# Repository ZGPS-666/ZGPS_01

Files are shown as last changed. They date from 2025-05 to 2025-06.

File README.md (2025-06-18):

# ZGPS_01
一种可在球形和六足形态切换的可变形机器人设计与开发

本项目旨在尝试复刻项目MorpHex，原作者ZentaRobotics视频主页如下：https://www.youtube.com/@ZentaRobotics

3D模型文件请使用solidworks 2024及以上版本打开，钣金件所需数目已在文件名标注，3D打印可转至makerworld，已切片，方便打印:https://makerworld.com.cn/zh/models/1331257-qiu-xing-liu-zu-shuang-xing-tai-ji-qi-ren#profileId-1434366

PCB工程请转至嘉立创EDA：https://oshwhub.com/zgps/spherical-hexapod-biped-robot

## 视频链接：
[B站视频--功能演示及介绍](https://www.bilibili.com/video/BV1fMJgzxEva/)
## 项目简介
一种可在球形和六足形态切换的可变形机器人设计与开发

本项目旨在尝试复刻项目morphex，同时作为本人本科毕业设计题目，原作者视频主页如下：https://www.youtube.com/@ZentaRobotics

项目源码及3D模型请转至GitHub：
https://github.com/ZGPS-666/ZGPS_01

## 项目功能
作为本人首个独立完成的完整机器人系统项目，在有限的开发周期内，项目重点聚焦于核心功能的复现与验证。当前版本已成功实现机器人的基本运动能力，包括六足步态行走、球形滚动和形态切换功能。

本设计是基于STM32F407ZGT6微控制器的多形态变形机器人系统，使用STM32CUBEIDE开发：
- **六足行走模式**：支持直线前进、侧向移动、原地旋转等多种运动方式，采用三角步态实现稳定行走；
- **球形滚动模式**：通过12个切片的协调控制实现前进、后退、左转、右转等全方向滚动运动；
- **自动变形功能**：实现两种形态间的平稳切换；
- **多种控制方式**：支持遥控器控制和语音识别控制，提供灵活的人机交互方式；

## 项目参数
* 六足模式行走速度：≥0.2m/s，具备全向移动和精确转向能力；
* 球形模式滚动速度：≥0.5m/s，运动效率显著提升；
* 形态切换时间：<30秒，具有较高的成功率和可靠性；
* 球形结构直径：400mm，由6个环向分布的可控切片组成；
* 驱动系统：30个20kg·cm串口总线舵机 + 1个70kg·cm数字舵机；
* 工作电压：7.4V，续航能力：9000mAh大容量航模电池；
* 通信方式：2.4GHz无线遥控 + 离线语音识别；

## 原理解析（硬件说明）
本项目由以下核心部分组成：主控制系统、驱动系统、变形机构、通信系统和供电系统。
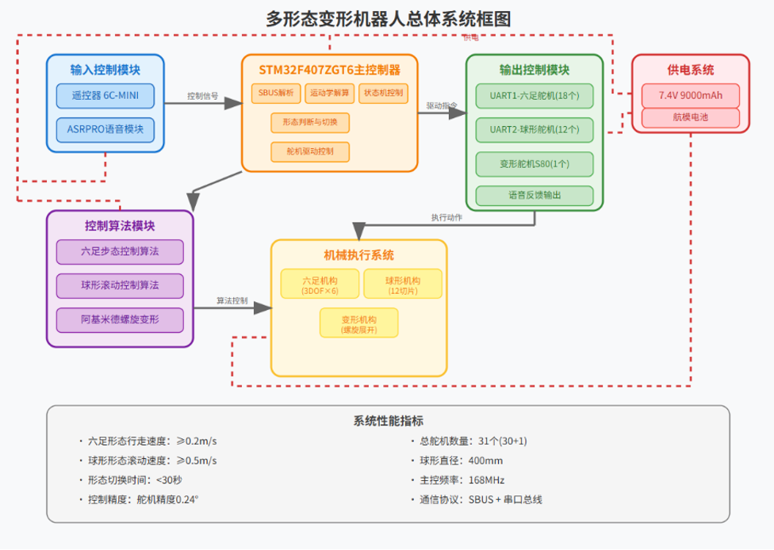
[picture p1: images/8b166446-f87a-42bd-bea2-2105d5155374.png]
  

**主控制系统**：采用STM32F407ZGT6微控制器，168MHz主频，1M Flash + 192K SRAM，提供6个UART接口满足多舵机通信需求。集成了运动学解算、步态控制、形态切换等核心算法。

**驱动系统电路**：使用AIP74HC126TA.TB四路三态缓冲器实现串口信号的电平转换和驱动增强。30个ZX20D总线舵机负责腿部运动和切片控制，1个S80舵机专门驱动变形机构，满足大扭矩变形需求。

**变形机构设计**：核心采用阿基米德螺旋原理设计的底盘展开机构，通过螺旋形切片在齿轮系统驱动下的轴向旋转，实现六条腿的同步展开和收缩，确保形态切换的稳定性和可靠性。

**通信系统电路**：集成Microzone 6C-MINI遥控器系统，通过MC7RB-V2接收机实现2.4GHz无线控制。SBUS信号经过硬件电平反转电路处理后接入主控。同时集成ASRPRO语音模块，支持离线语音识别控制。

**供电系统**：采用7.4V/9000mAh/10C大功率航模电池，满足六足行走模式下的高功率需求，通过PCB上的电源管理电路为各模块提供稳定供电。

## 软件代码
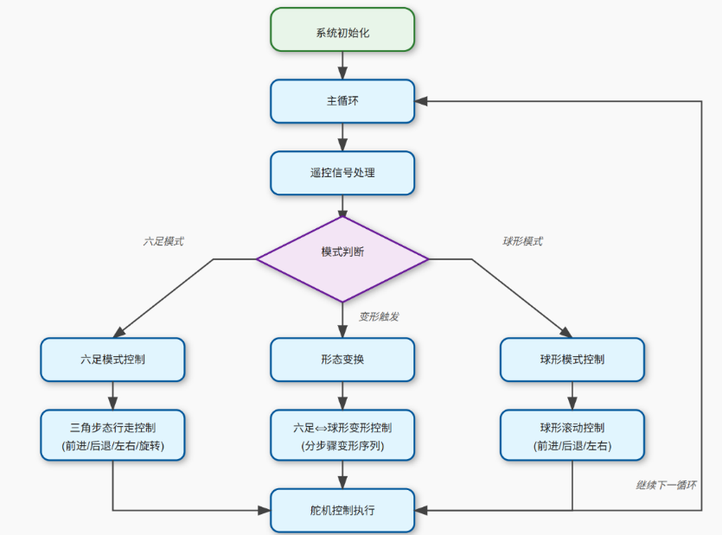
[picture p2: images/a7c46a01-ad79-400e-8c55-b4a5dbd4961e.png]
  
完整代码请参考：(https://github.com/ZGPS-666/ZGPS_01)

## 注意事项

* 所有安装步骤前请先完成总线舵机编号并调至中位，工作模式选择模式一，开机模式选择模式三
* 所有安装步骤前请把中央舵机先设置至30°位置
* 遥控器使用前需要与接收机进行配对，注意SBUS信号的电平转换；
* 电池电压低于6.8V时应及时充电，避免影响大扭矩舵机性能；

## 组装流程
待更新

## 实物图
图1：**六足形态** - 机器人完全展开的六足行走状态
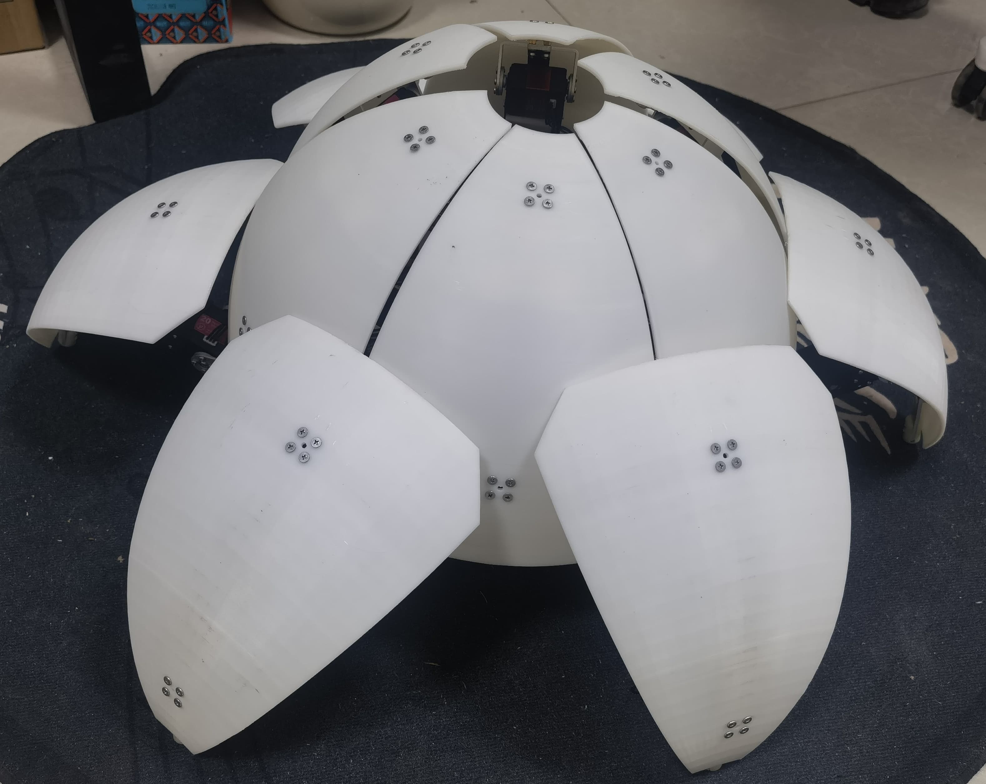
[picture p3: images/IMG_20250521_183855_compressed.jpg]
  

图2：**球形态** - 机器人收缩后的球形滚动状态  
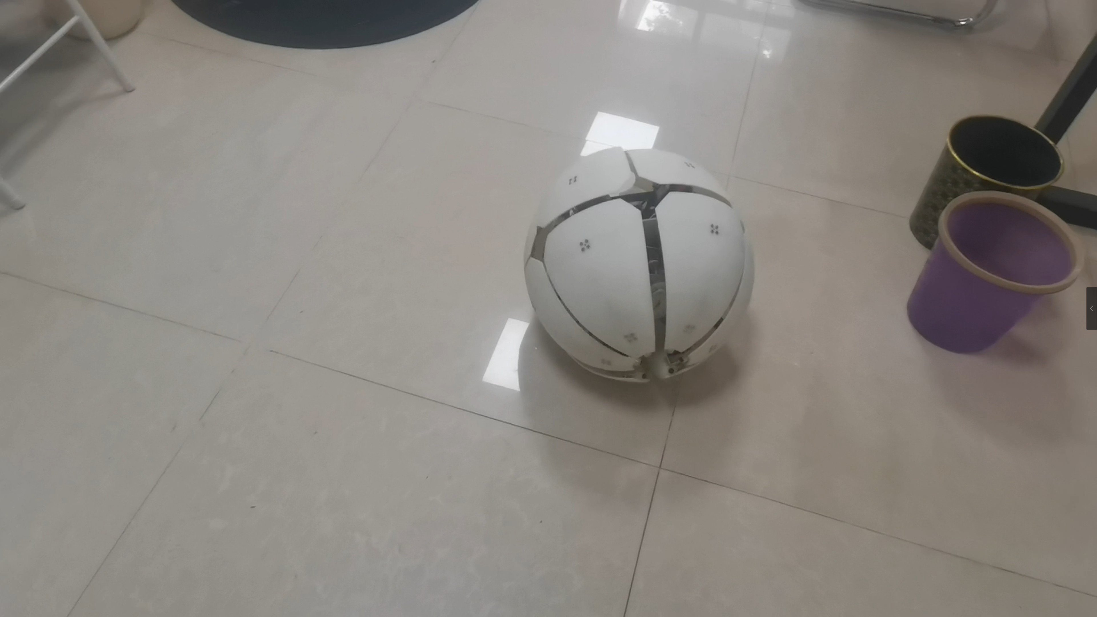
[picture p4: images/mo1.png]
  

图3：**展示模式** - 从六足向球形转换的中间状态
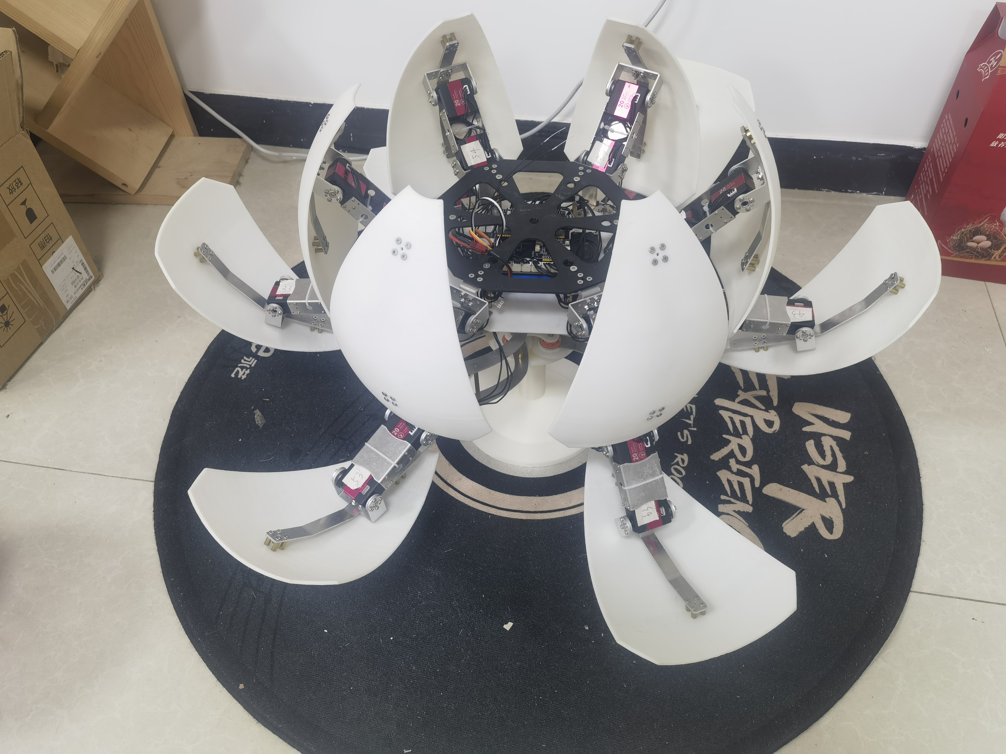
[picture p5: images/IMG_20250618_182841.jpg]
  

## 声明
由于本人水平有限，初次独立完成完整项目，时间仓促，仅完成机器人的基本功能，代码已有堆史山的趋势，所以本项目只能保证机器人能动。

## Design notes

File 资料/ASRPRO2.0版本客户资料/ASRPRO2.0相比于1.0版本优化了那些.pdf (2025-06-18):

我们汲取客户的反馈，对电路进行优化，推出 ASRPRO2.0 版本。

其 ASRPRO 语音识别模块 2.0 版本相比于 1.0，其外形上尺寸继续

延续 1.0 版本，其内部电路进行了优化。

下面详细介绍，2.0 版本都进行了那些优化。

1. 2.0 版本在 5V 和 3.3V 之前加入了 TVS 二极管防止电源过压，保

护芯片。

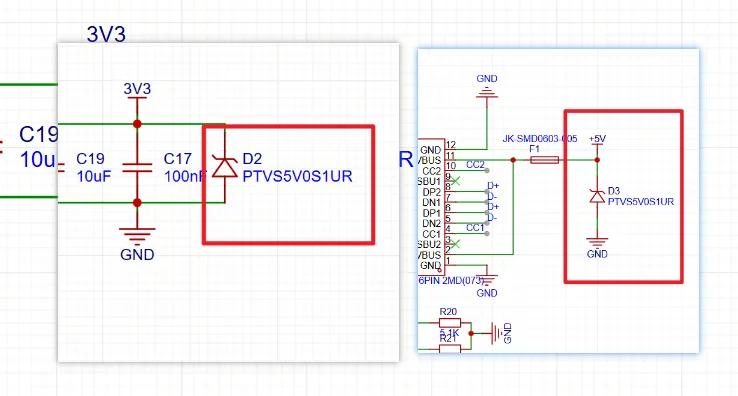
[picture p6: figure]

### 2. ASRPRO-1.0 版本上的 3.3V 输出引脚是由芯片内部引出的，很

多客户接外设时，把 GND 和 VCC 接反会直接烧毁主控芯片。而

ASRPRO-2.0 版本的 3.3V 输出引脚是 LDO 电路输出的，极大的保

护了主控芯片。其次 LDO 输出的电流比主控芯片输出的电流大，因

此 2.0 版本 3.3V 引脚的驱动能力更强。

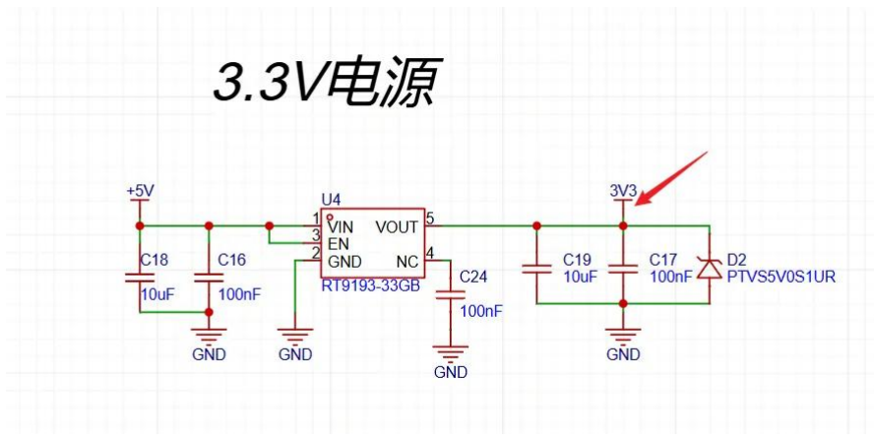
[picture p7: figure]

### 3. 在处理 ASRPRO-1.0 版本的售后时，常会有客户反应，为什么我

开发板下载程序会显示“请是否连接设备 ASR-PRO”。这是因为

ASRPRO 开发板内部一键下载电路出现了问题，无法进行冷启动，

因此在 ASRPRO-2.0 版本上加入了手动下载按键，出现以上情况时，

可以按下按键进行手动冷启动，确保程序能够正常下载。

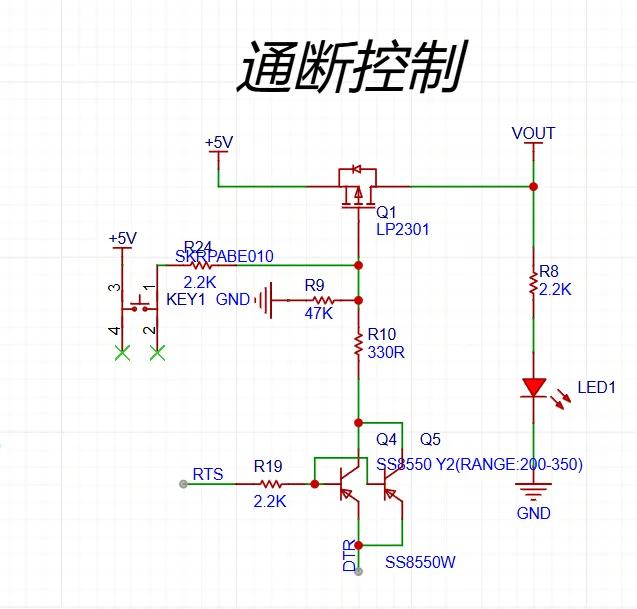
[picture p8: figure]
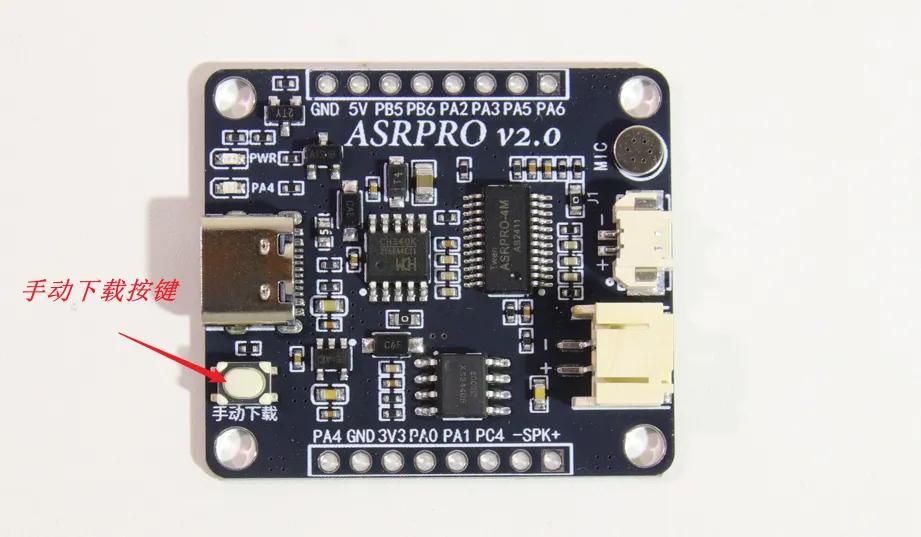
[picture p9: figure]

### 4. 常有客户把 ASRPRO 加上外壳，放到自己的产品中使用，这时

板载的麦克风外面有外壳包裹，导致麦克风识别不灵敏，会影响识别

率。 ASRRPO-2.0 版本加入了 1.25mm 间距麦克风底座，可以用来

外接麦克风,也可以使用板载麦克风，更好的嵌入到产品中，应用场

景更加广泛。

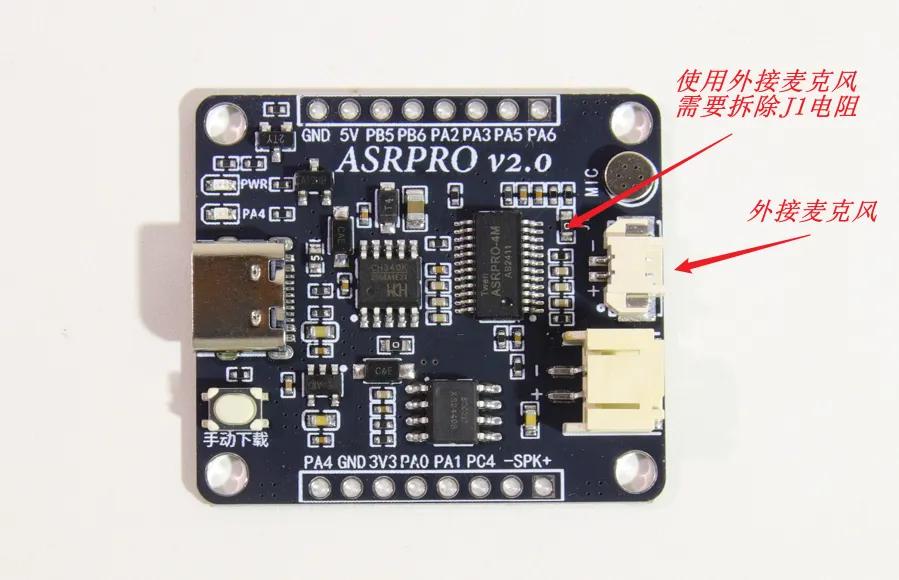
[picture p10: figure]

5.

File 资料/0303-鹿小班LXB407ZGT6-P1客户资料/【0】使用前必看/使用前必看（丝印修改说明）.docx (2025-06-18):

这里丝印标错 E13丝印实际指的是F13

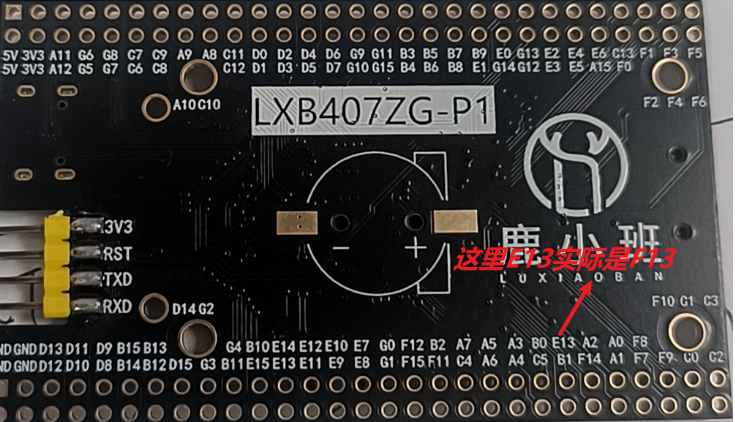
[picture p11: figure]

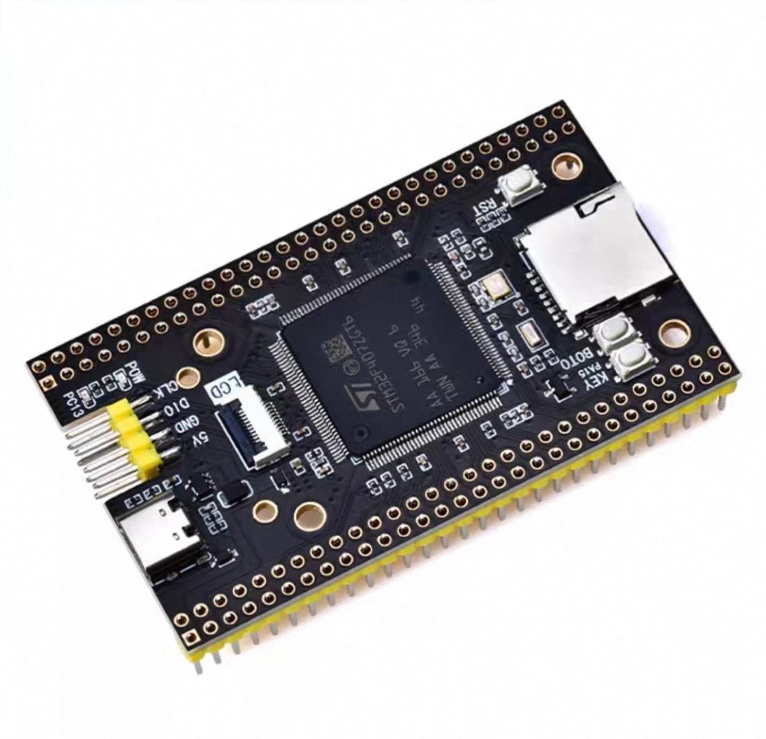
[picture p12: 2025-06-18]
资料/0303-鹿小班LXB407ZGT6-P1客户资料/【4】原理图尺寸图/Screenshot_20250314_162414.jpg

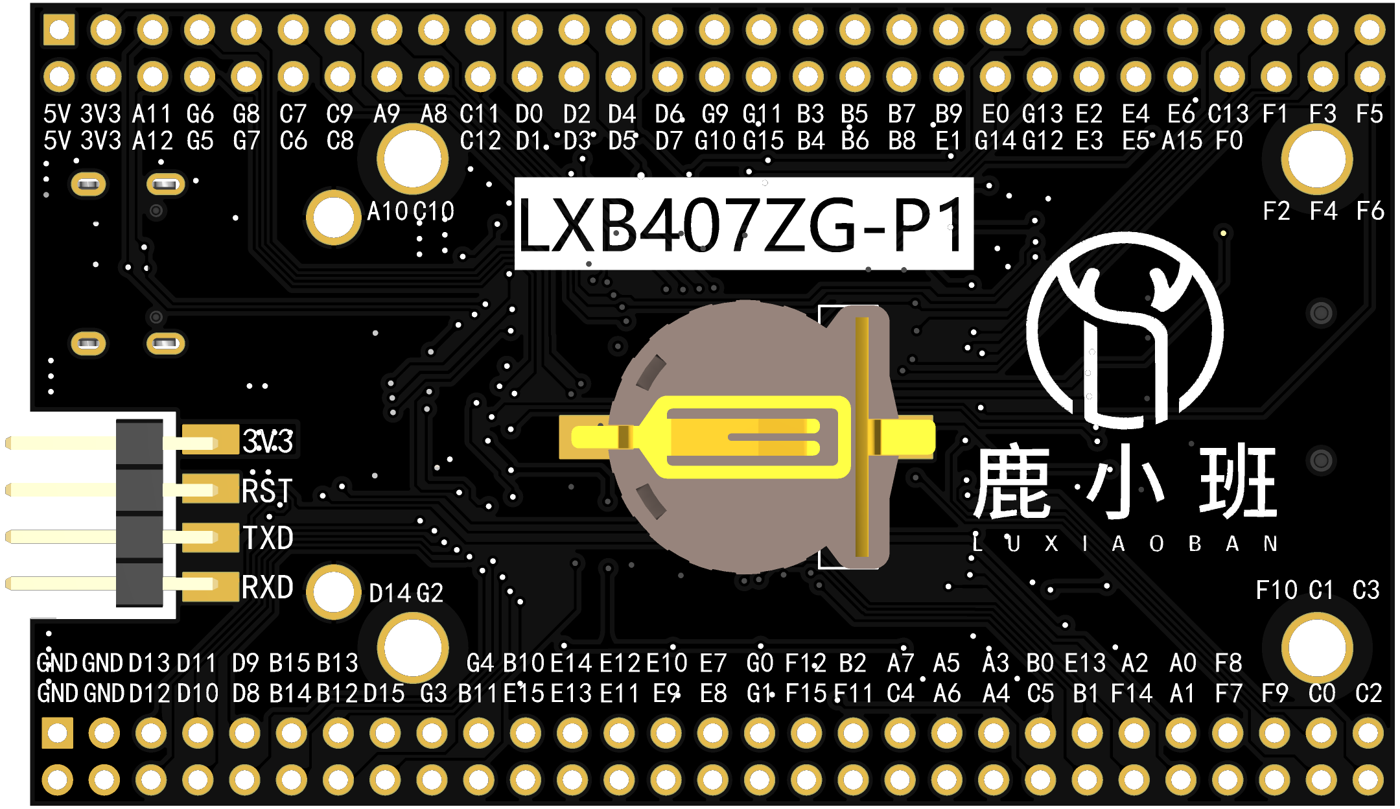
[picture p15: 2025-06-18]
资料/0303-鹿小班LXB407ZGT6-P1客户资料/【4】原理图尺寸图/反面.png

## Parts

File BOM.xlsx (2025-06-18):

物料编号 | 物料描述 | 数量 | 成本 | 总成本 | 备注
1 | 松甲 串行总线舵机 ZX20D | 30 | 66.8 | 1945
2 | 串行舵机连接线 50cm | 6 | 4 | 24
3 | 串行舵机连接线 30cm | 6 | 3 | 18
4 | 星辉S80 180°舵机 | 1 | 288 | 288 | 大扭矩带堵转保护舵机
5 | microzone MC6C遥控器+接收器+电池 | 1 | 150 | 150
6 | 十字扁平头螺丝M3*6 | 200 |  | 13.9 | 螺栓螺母部分数量为我购买数量，实际用不到那么多
7 | 十字扁平头螺丝M3*8 | 300 |  | 23.5
8 | 十字扁平头螺丝M3*10 | 50 |  | 2.9
9 | 十字扁平头螺丝M3*12 | 50 |  | 3.3
10 | 十字扁平头螺丝M2*12 | 50 |  | 2.1
11 | 六角螺母M3 | 200 |  | 5.5
12 | 六角螺母M4 | 100 |  | 4.2
13 | 圆柱头螺栓内六角M3*14 | 50 |  | 2.3
14 | 圆柱头螺栓内六角M3*8 | 50 |  | 3.3
15 | 圆柱头螺栓内六角M4*16 | 20 |  | 2.6
16 | 圆柱头螺栓内六角M4*20 | 40 |  | 7
17 | 圆柱头螺栓内六角M4*25 | 20 |  | 4.2
18 | 圆柱头螺栓内六角M4*30 | 20 |  | 4.5
19 | 圆柱头螺栓内六角M3*10 | 100 |  | 5
20 | 金属25T舵机舵盘 | 30 | 1.3 | 39
21 | 双轴舵机副舵盘 | 30 | 1.3 | 39
22 | 双轴短U支架 | 6 | 2.5 | 15
23 | 双轴长U支架 | 24 | 2.5 | 60
24 | 无线仿真器一对 | 1 | 79 | 79 | 方便调试，可不使用
25 | 六角铜柱M3*25 | 50 | 13.2 | 13.2 | 铜柱部分数量为我购买数量，实际用不到那么多
26 | 六角铜柱M3*10 | 200 | 8.5 | 17
27 | 六角铜柱M4*35 | 20 | 10 | 10
28 | 六角铜柱M4*55 | 10 | 9.4 | 9.4
29 | 六角铜柱M3*55 | 20 | 12.8 | 12.8
30 | 六角铜柱M4*25 | 20 | 8.4 | 8.4
31 | 鹿小班 STM32F407ZGT6核心板 | 1 | 57 | 57
32 | ASRPRO2.0开发板4M版本+喇叭 | 1 | 29 | 29 | 可不使用
33 | 半球形硅胶脚垫 直径9.8mm*厚5mm 100粒 | 1 | 8.5 | 8.5
34 | T型公头 14AWG 10cm | 1 | 4.1 | 4.1
35 | 2S3P 10C 9000毫安 6节横排 T头+XH3P双插头 18650锂电7.4V | 1 | 80 | 80
36 | 锂电池平衡充电器 | 1 |  | 15 | 电池容量大，建议购买
37 | 上部舵机支架 | 6 | 4.75 | 28.5 | 以下为钣金件，在嘉立创选择5052铝合金
38 | 旋臂 | 12 | 4.78 | 57.36
39 | 下外壳固定件 | 6 | 4.5 | 27
40 | 上外壳固定件 | 6 | 3.87 | 23.22
41 | 外壳固定件 | 12 | 4.25 | 51
42 | 舵机连接件 | 12 | 3.94 | 47.28
43 | 三绿ABS耗材1KG | 3 | 40 | 120
 |  |  |  | 3360.06

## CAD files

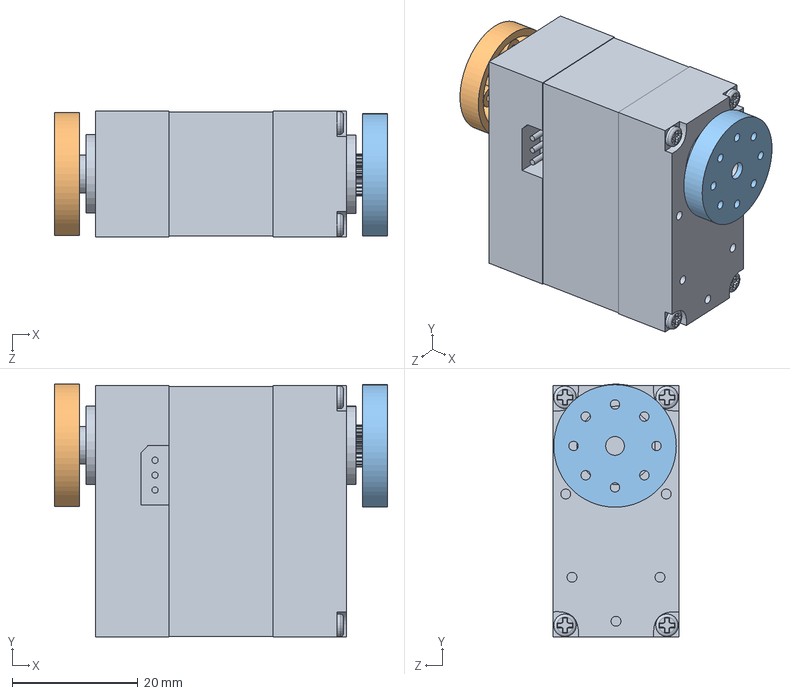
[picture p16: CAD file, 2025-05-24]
3D建模/总线舵机塑料主从舵盘.SLDASM
53.0 x 40.2 x 20.0 mm
总线双轴舵机
塑料从舵盘
塑料主舵盘

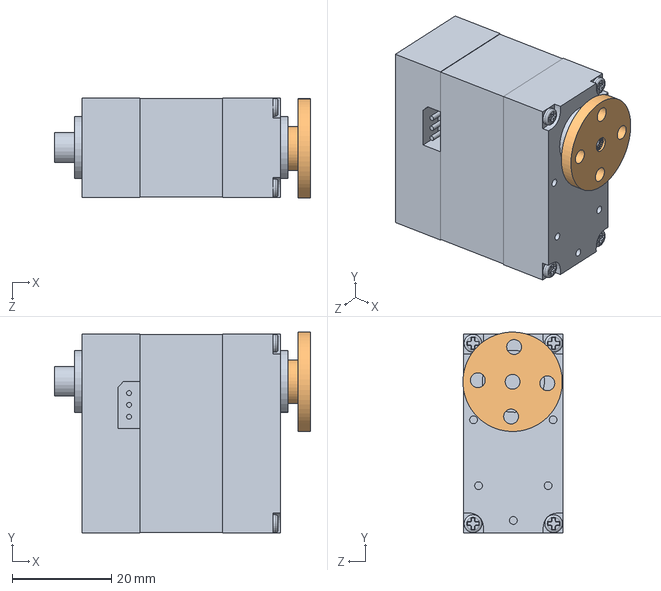
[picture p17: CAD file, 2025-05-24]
3D建模/装配体15.SLDASM
51.5 x 40.4 x 20.1 mm
总线双轴舵机
金属主舵盘

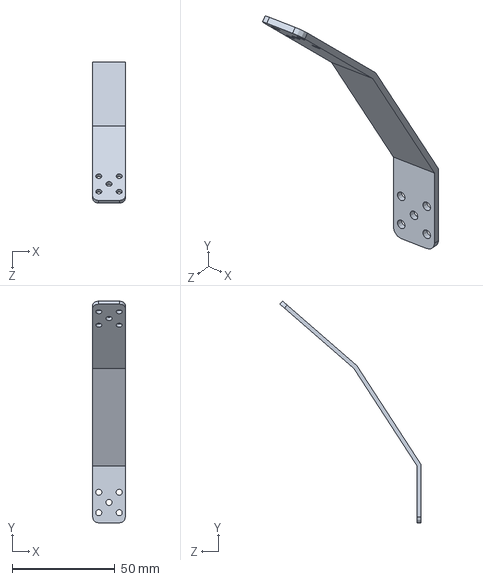
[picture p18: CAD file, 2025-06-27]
3D建模/外壳固定件_1.SLDPRT
16.0 x 108.0 x 68.8 mm

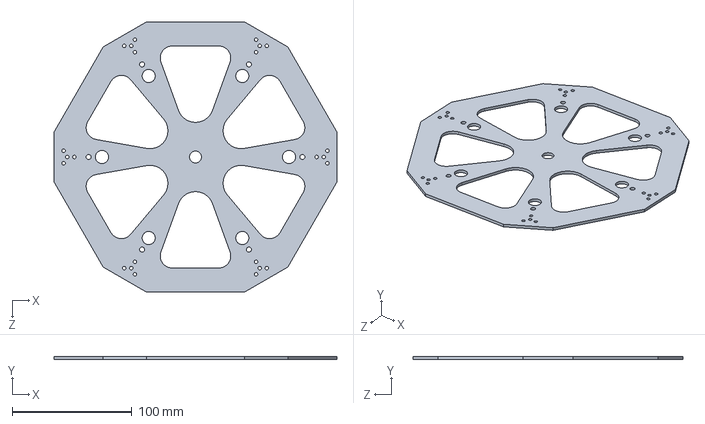
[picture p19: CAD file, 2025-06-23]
3D建模/底板_4_2.SLDPRT
236.0 x 2.50 x 225.2 mm

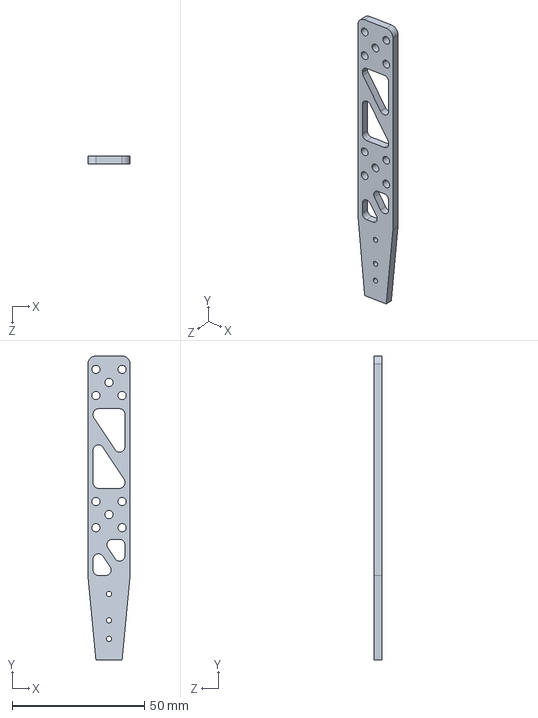
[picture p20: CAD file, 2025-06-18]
3D建模/钣金/外壳固定件_down_6.STEP
16.0 x 115.0 x 3.00 mm

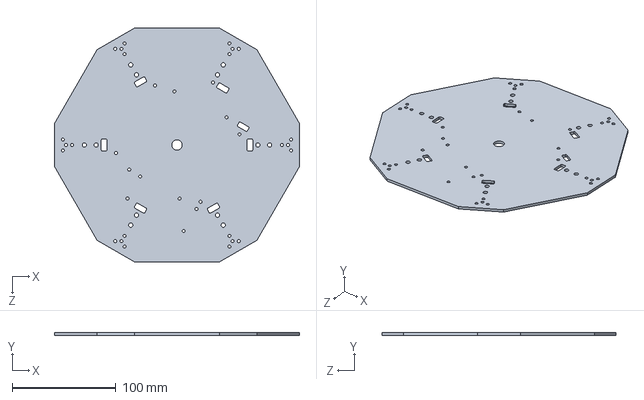
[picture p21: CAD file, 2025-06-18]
3D建模/底板_4.SLDPRT
236.0 x 2.50 x 225.2 mm

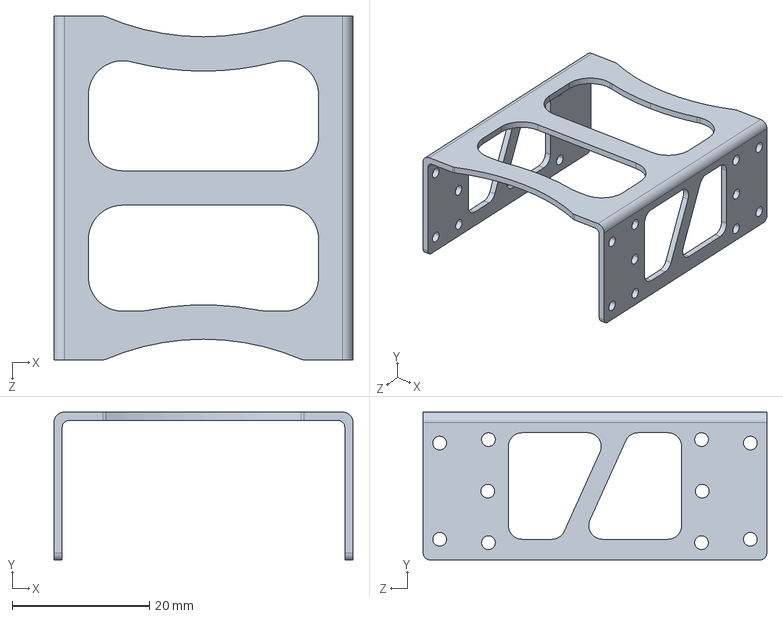
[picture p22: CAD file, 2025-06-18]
3D建模/钣金/小U连接件_12.STEP
43.5 x 21.5 x 50.0 mm

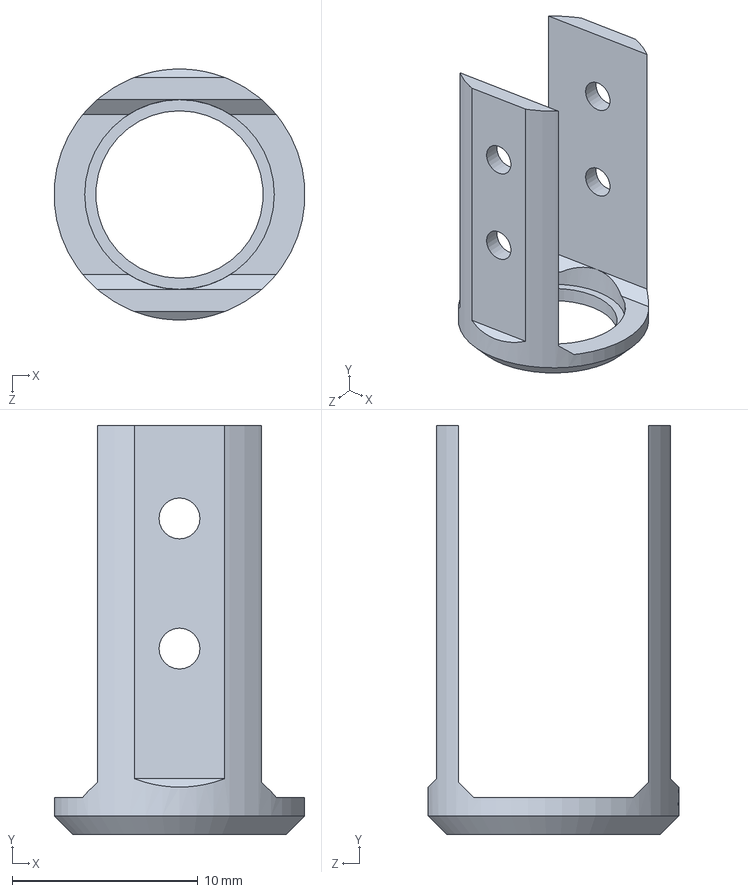
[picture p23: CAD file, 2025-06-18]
3D建模/foot_2.SLDPRT
13.5 x 22.0 x 13.5 mm

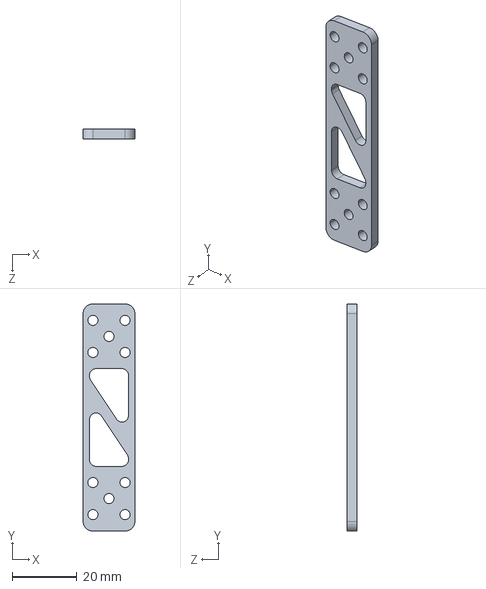
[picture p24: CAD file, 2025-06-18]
3D建模/钣金/外壳固定件_up_6.STEP
16.0 x 70.0 x 3.00 mm

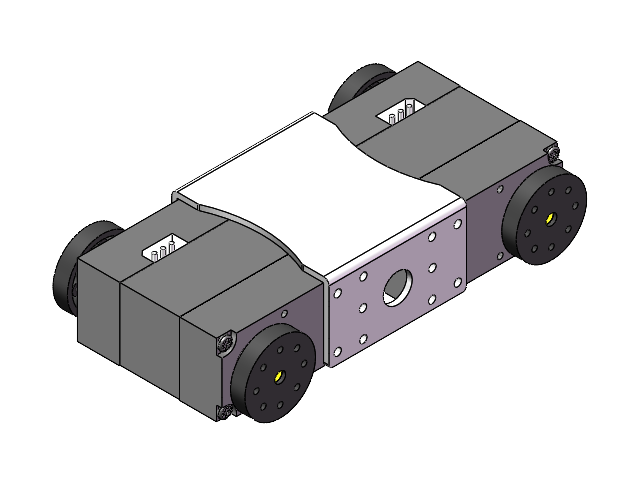
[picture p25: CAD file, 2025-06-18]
3D建模/小u连接2总线舵机.SLDASM
小U连接件_改
总线双轴舵机 x 2
塑料从舵盘 x 2
塑料主舵盘 x 2

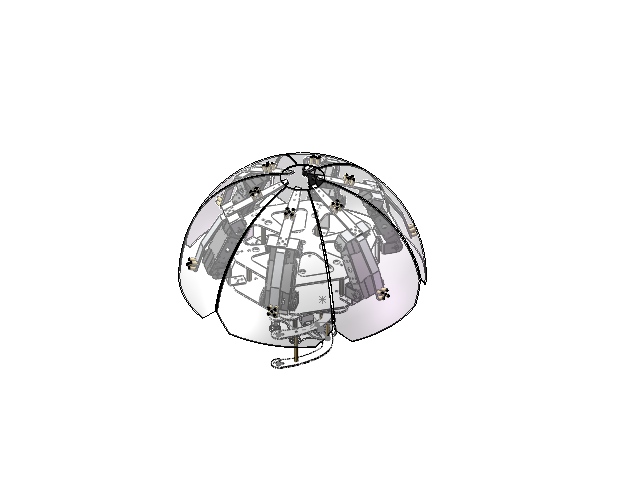
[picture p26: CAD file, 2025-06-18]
3D建模/展开机构.SLDASM
底板_1
底板_3
底板-2-1
舵机_2
gear-z
铜柱M4_15 x 6
上部舵机支架_1 x 6
底板_4
铜柱M4_60 x 6
小U连接件 x 6
总线双轴舵机 x 12
塑料从舵盘 x 12
塑料主舵盘 x 12
宽U支架 x 6
双轴舵机超长U型架 x 6
球壳 x 6
足_下部 x 6
M3铜柱10 x 48
下外壳固定件_ x 6
底板_5
垫圈_2 x 2
垫圈_4
gear - 2
铜柱M3_55 x 2
垫圈
arm板 x 2
铜柱M4_35 x 6
底板_4_2

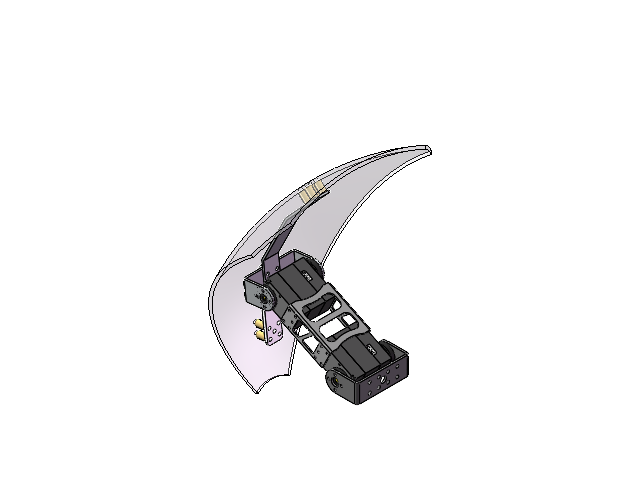
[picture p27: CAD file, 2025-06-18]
3D建模/腿部_UP.SLDASM
小U连接件_改
总线双轴舵机 x 2
塑料从舵盘 x 2
塑料主舵盘 x 2
宽U支架
双轴舵机超长U型架
球壳
M3铜柱10 x 8
外壳固定件_1
外壳固定件_up

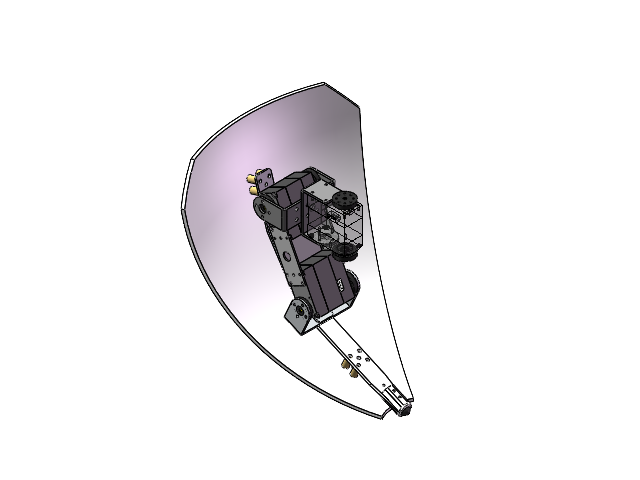
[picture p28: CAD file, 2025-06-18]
3D建模/腿部_down.SLDASM
小U连接件_改
总线双轴舵机 x 3
塑料从舵盘 x 3
塑料主舵盘 x 3
宽U支架
双轴舵机超长U型架
球壳
外壳固定件_down
M3铜柱10 x 8
外壳固定件_1
窄U支架
防滑垫
foot_2
foot_3 x 2

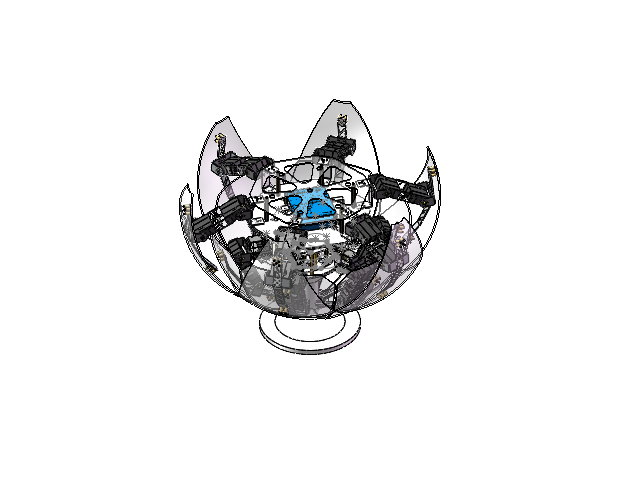
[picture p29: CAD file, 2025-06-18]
3D建模/morphex.SLDASM
底板_1
底板_3
底板-2-1
舵机_2
gear-z
铜柱M4_25 x 10
上部舵机支架_1 x 6
底板_4
小U连接件_改 x 12
总线双轴舵机 x 30
塑料从舵盘 x 30
塑料主舵盘 x 30
宽U支架 x 12
双轴舵机超长U型架 x 12
球壳 x 12
外壳固定件_down x 6
M3铜柱10 x 96
外壳固定件_1 x 12
窄U支架 x 6
防滑垫 x 6
foot_2 x 6
foot_3 x 12
铜柱M4_55 x 6
外壳固定件_up x 6
底板_5
垫圈_2 x 12
垫圈_4 x 3
gear - 2 x 6
铜柱M3_55 x 12
垫圈 x 6
arm板 x 12
铜柱M4_35 x 6
底板_4_2
垫圈3 x 3
电池固定架1
电池固定架2
PCB3D
电池
接收器固定架
展示架

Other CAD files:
3D建模/arm_装配体_1.SLDASM
3D建模/arm_装配体_2.SLDASM
3D建模/装配体1.SLDASM
3D建模/钣金/外壳固定件_12.STEP
3D建模/M3铜柱10.SLDPRT
3D建模/PCB3D.SLDPRT
3D建模/arm板.SLDPRT
3D建模/foot_3.SLDPRT
3D建模/gear - 2.SLDPRT
3D建模/gear-z.SLDPRT
3D建模/gear.SLDPRT
3D建模/上部舵机支架_1.SLDPRT
3D建模/化简腿部抽象模型.SLDPRT
3D建模/双轴舵机超长U型架.SLDPRT
3D建模/垫圈.SLDPRT
3D建模/垫圈3.SLDPRT
3D建模/垫圈_2.SLDPRT
3D建模/垫圈_4.SLDPRT
3D建模/塑料主舵盘.SLDPRT
3D建模/塑料从舵盘.SLDPRT
3D建模/外壳固定件_down.SLDPRT
3D建模/外壳固定件_up.SLDPRT
3D建模/宽U支架.SLDPRT
3D建模/小U连接件_改.SLDPRT
3D建模/展示架.SLDPRT
3D建模/底板-2-1.SLDPRT
3D建模/底板_1.SLDPRT
3D建模/底板_3.SLDPRT
3D建模/底板_5.SLDPRT
3D建模/总线双轴舵机.SLDPRT
3D建模/接收器固定架.SLDPRT
3D建模/支架_1.SLDPRT
3D建模/球壳.SLDPRT
3D建模/电池.SLDPRT
3D建模/电池固定架1.SLDPRT
3D建模/电池固定架2.SLDPRT
3D建模/窄U支架.SLDPRT
3D建模/简化.SLDPRT
3D建模/腿部简化_1.SLDPRT
3D建模/舵机_2.SLDPRT
3D建模/舵盘垫圈.SLDPRT
3D建模/钣金/arm板_12.STEP
3D建模/钣金/上部舵机支架_6.STEP
3D建模/铜柱M3_55.SLDPRT
3D建模/铜柱M4_25.SLDPRT
3D建模/铜柱M4_35.SLDPRT
3D建模/铜柱M4_55.SLDPRT
3D建模/防滑垫.SLDPRT
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

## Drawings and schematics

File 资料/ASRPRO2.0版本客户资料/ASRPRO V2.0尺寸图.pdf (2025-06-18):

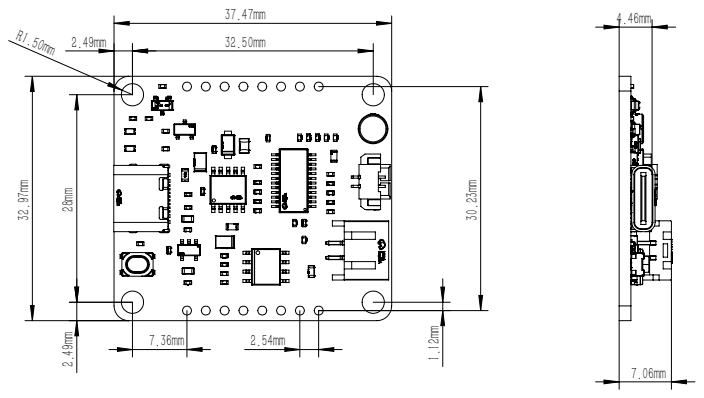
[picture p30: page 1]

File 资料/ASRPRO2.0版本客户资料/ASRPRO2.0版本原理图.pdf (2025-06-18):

# MCU AEC

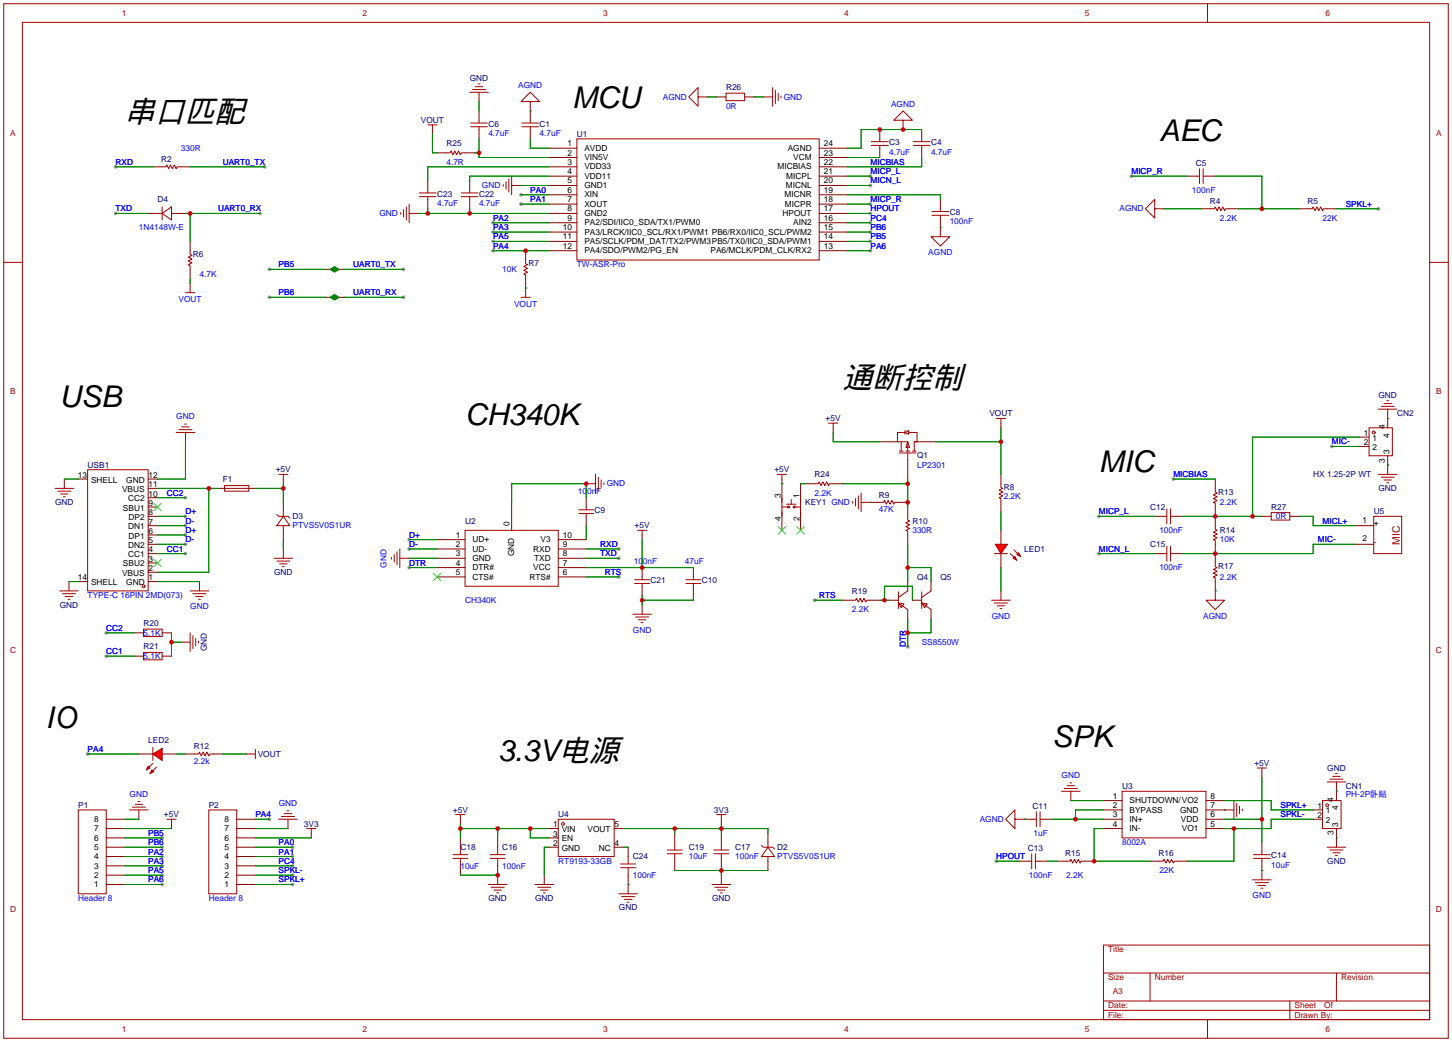
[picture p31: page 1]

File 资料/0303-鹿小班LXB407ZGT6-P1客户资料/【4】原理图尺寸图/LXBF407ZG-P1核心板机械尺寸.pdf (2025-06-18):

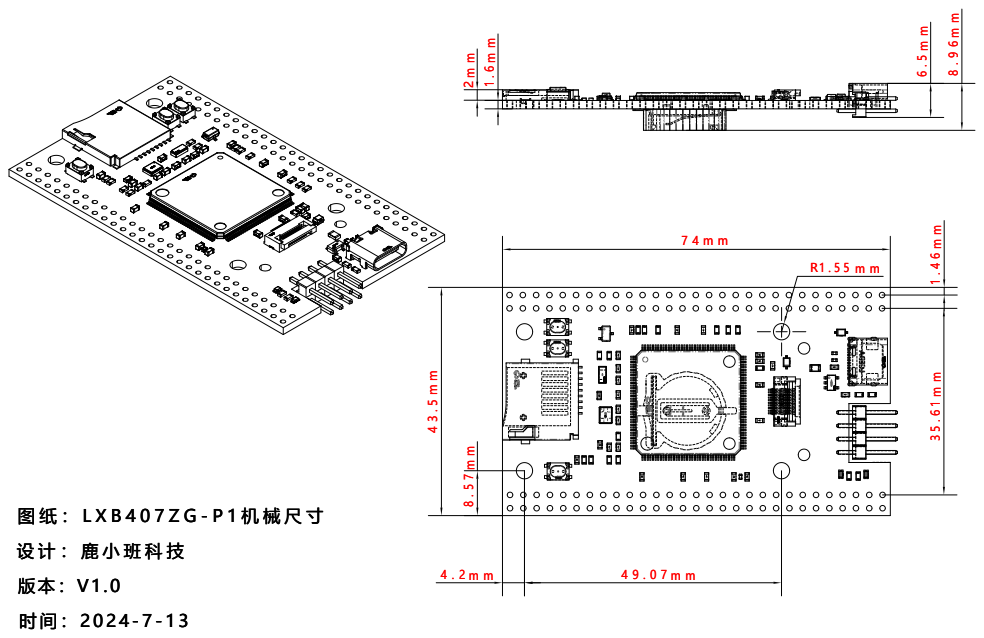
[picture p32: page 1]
图纸：LXB407ZG-P1机械尺寸; 设计：鹿小班科技
